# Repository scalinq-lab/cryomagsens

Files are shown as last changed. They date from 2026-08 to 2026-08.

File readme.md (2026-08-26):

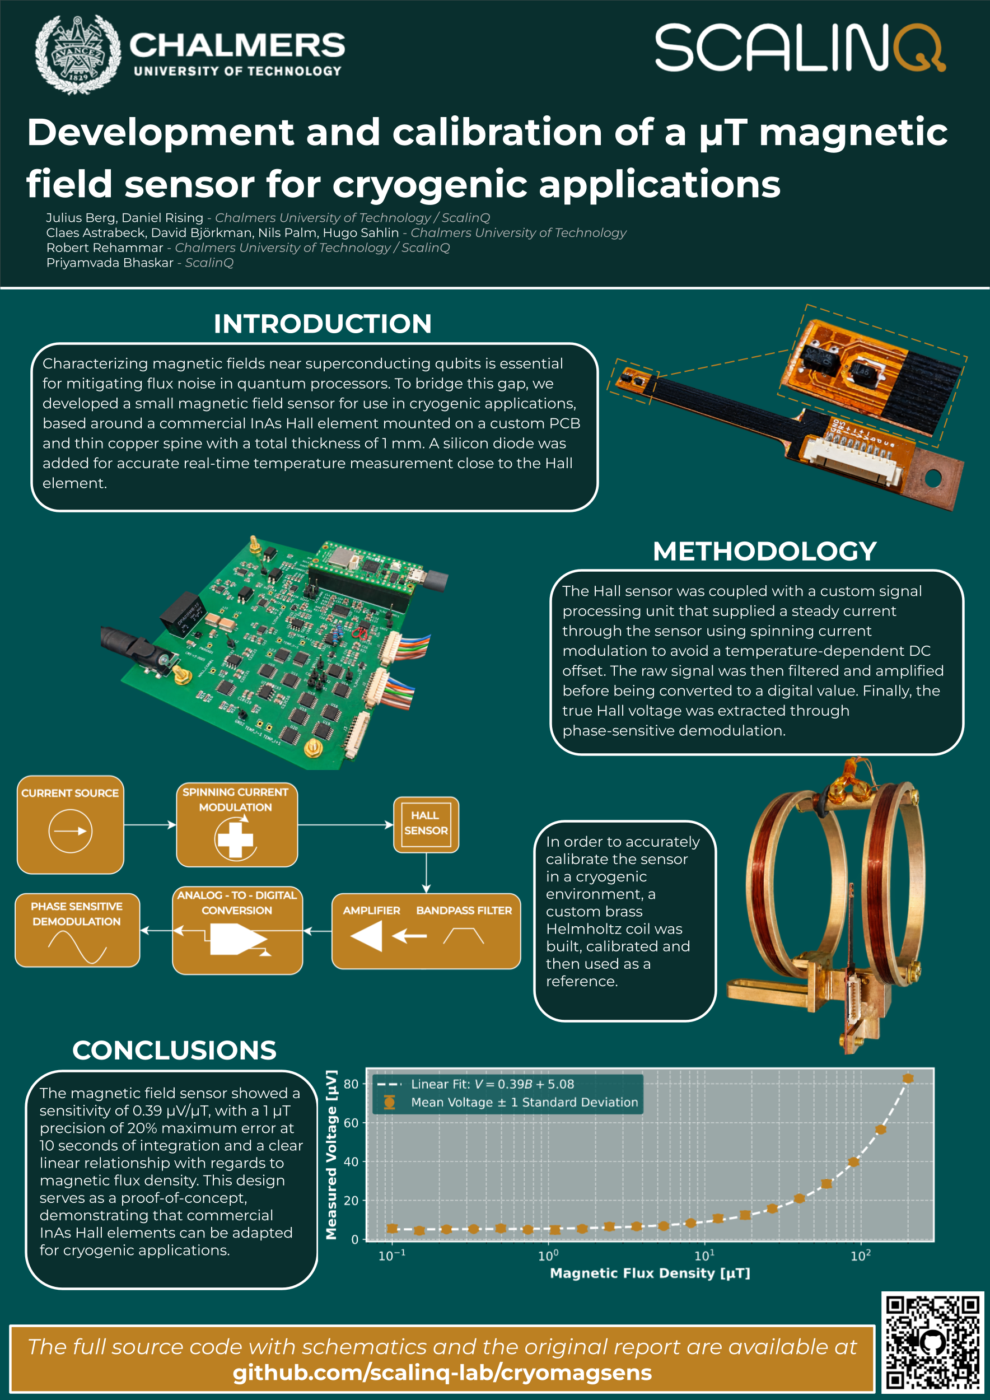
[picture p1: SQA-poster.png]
Photo of the poster from SQA

*(Poster from presentation at SQA conference 2026)*

# Cryomagsens

## Project History
This repository is [SCALINQ AB's](https://www.scalinq.com/) continuation of a project that originally began as a Bachelor's Thesis project at the 
 [Department of Microtechnology and Nanoscience at Chalmers University of Technology](https://www.chalmers.se/en/departments/mc2/), 
 in collaboration with SCALINQ AB.

The original proof-of-concept repository can be referenced for historical context [here](
https://github.com/cryomagsens/cryomagsens)

## Description
Cryomagsens is a magnetic field sensor, developed specifically for cryogenic applications. It features a custom sensor 
built around the AKM HQ0811 InAs Hall effect sensor with an integrated temperature sensor and a custom signal processing
unit (SPU), using phase sensitive detection to extract the signal. The signal processing unit is built around the 
Raspberry Pi Pico 2W microcontroller development board, and features hardware support for measurements with 3 different 
sensor units at once.

The system also includes a custom built brass Helmholtz coil for controlled calibration in a cryogenic environment.

All PCB design files for the signal processing unit can be found in `/signal_processing_unit_pcb`, 
and all the PCB design files for the sensor unit can be found in `/sensor_unit_pcb`.

All the mechanical files for the Helmholtz coil and custom PCB mounts can be found in `/mechanical_designs`.

The signal processing unit firmware can be found in `/signal_processing_unit_firmware` and the calibration and test
scripts can be found in `/calibration_scripts`.

## Results
Experimental results show a sensitivity of 0.39 V/T at 5.2 K and 300 µA drive current, with a 20 % relative error at 1 µT.

## Known issues
During work with the project, we have encountered the following problems:

* When running the calibration system at low temperatures, significant self heating occurs. The sensor itself has a low thermal load for currents up to 3 mA through the hall sensor, but thermalizes badly through the brass Helmholtz coil.
* After spinning current demodulation, a significant DC component remains to the signal, corresponding to ~10 µT of signal strenght.
* Uncertain temperature calibration, as mounting point for external temperature sensor is far from the integrated sensor.
* Possible self-induced magnetic fields on the sensor PCB due to signal path asymmetry.

The following is a list of non implemented features.
* No check for current source saturation (even though the signal processing unit has hardware support for such a check)
* No way to load calibration data to the SPU. Right now the SPU returns a voltage instead of a magnetic flux density.
* PCB design mistakes (fixed in the PCB design files but visible in the pictures).

The following is a list of proposed changes:
* Implement way to disable/enable current sources to the Hall element and diode independently without interfering with the ADC.
* Invert the connector signals (J1 - J3 on the signal processing unit PCB - Would make the cables bidirectional even when GND and PRS lines aren't shielded).
* Protect the sensitive signals between ground layers during the full signal path.   

## Licensing
This repository contains both software and hardware design files, licensed separately:

- All software (located in `/signal_processing_unit_firmware` and `/calibration_scripts`) is licensed under the MIT License. See [LICENSE-MIT](LICENSE-MIT).

- All hardware design files (PCB Schematics, Layouts, 3D CAD models, etc.) (located in `/mechanical_designs`, `/sensor_unit_pcb`, and `/signal_processing_unit_pcb`) are licensed under the CERN Open Hardware Licence Version 2 - Permissive. See [LICENSE-CERN-OHL-P](LICENSE-CERN-OHL-P).

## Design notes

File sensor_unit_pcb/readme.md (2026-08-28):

# Sensor unit: Schematics and PCB Design

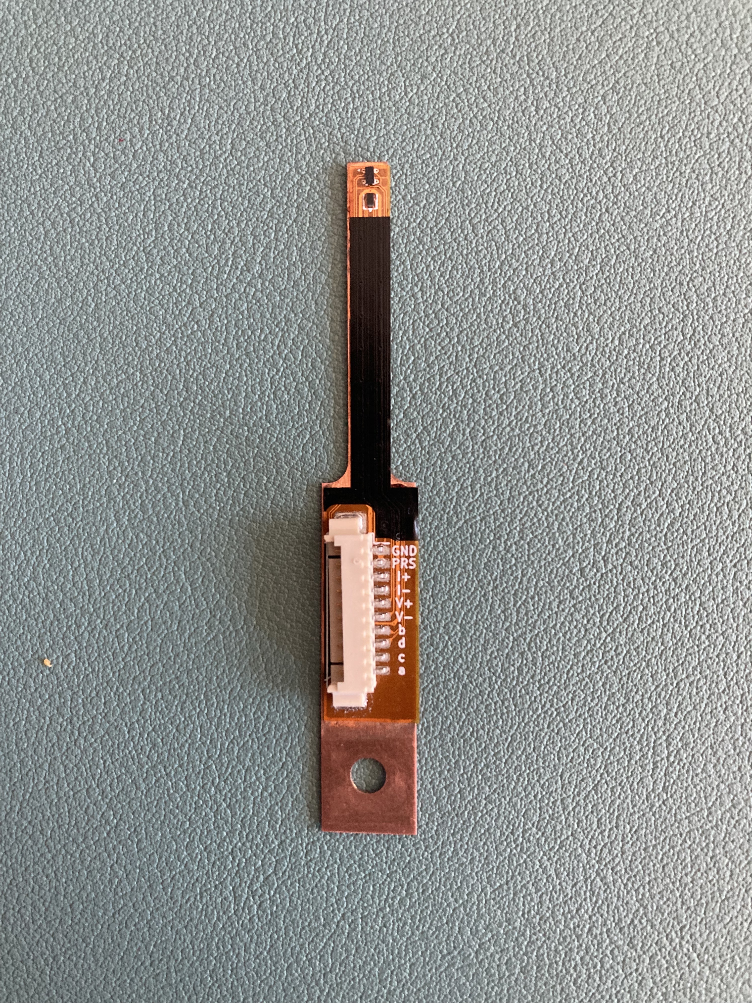
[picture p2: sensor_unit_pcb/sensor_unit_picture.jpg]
Sensor unit

*(Sensor unit)*

## Design

The sensor unit was designed in KiCad 10 and manufactured by JLCPCB. It is built in a flex PCB material to achieve 
a very small build height, in order to come very close to the device under test. The Flex PCB is mounted to a copper 
spine (see `..\mechanical_designs` for the full design) for thermalisation purposes. The total build height of the sensor unit is 1.1 mm.

The sensor unit features a AKM HQ0811 InAs Hall element as a magnetic field sensor, a 1N4148 Si diode as a temperature sensor and a 10-pin Molex PicoBlade connector for a good and stable connection.

## Working principle

### Hall sensor
The Hall element has four nodes, here denoted *a, b, c, d*. When a current is pushed fron *a* to *c*, a potential difference can be measured between *b* and *d*, which scales linearly with the applied orthogonal magnetic flux density.
When a current is pushed from *b* to *d*, a similar potential difference can be measured between *a* and *c*.
By modulating the current directiion and through which axis the current is pushed, the remaining DC offset due to asymmetries in the element can be eliminated.

### Diode temperature sensor
The sensor unit also features a 4-wire measurement setup for the diode, which acts as a temperature sensor.
The nominal drive current of the diode is 10 µA.

### Presence pin.
The sensor unit features a presence pin *(denoted PRS)*, which is internally connected to the ground pin on the sensor PCB.
When connected to the signal processing unit, a GPIO pin is pulled low through the sensor unit, indicating that 
a sensor is connected and allowing current output.

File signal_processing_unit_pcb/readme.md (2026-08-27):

# Signal Processing Unit: Schematics and PCB Design

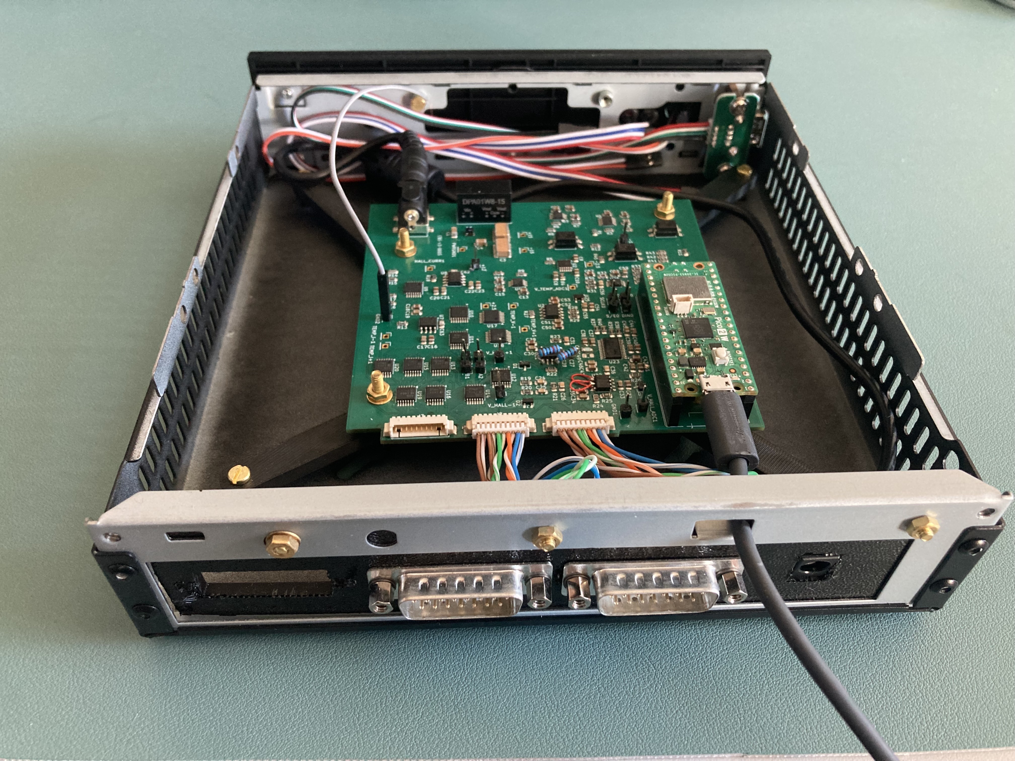
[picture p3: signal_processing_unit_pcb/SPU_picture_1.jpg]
Signal processing unit

*(Assembled signal processing unit)*

## Design

The signal processing unit *(SPU)* was designed in KiCad 10 and manufactured by JLCPCB. It is based around the Raspberry Pi Pico 2W development board and features hardware support for simultaneous magnetic field measurements from three separate cryomagsens sensor units. 

The SPU supports both USB and WiFi interfacing and is physically grounded to the chassis to minimize noise. Custom 3D models for components outside of the standard KiCad libraries were sourced from the SamacSys Library Loader.

## Cabling

The board features three 10-pin Molex PicoBlade connectors. These route to external 15-pin D-sub connectors on the enclosure to ensure a secure physical connection.

## Known Issues 

There are three known design mistakes on the physical PCB shown above. **Note:** All three issues have been corrected in the provided KiCad schematic and PCB design files.

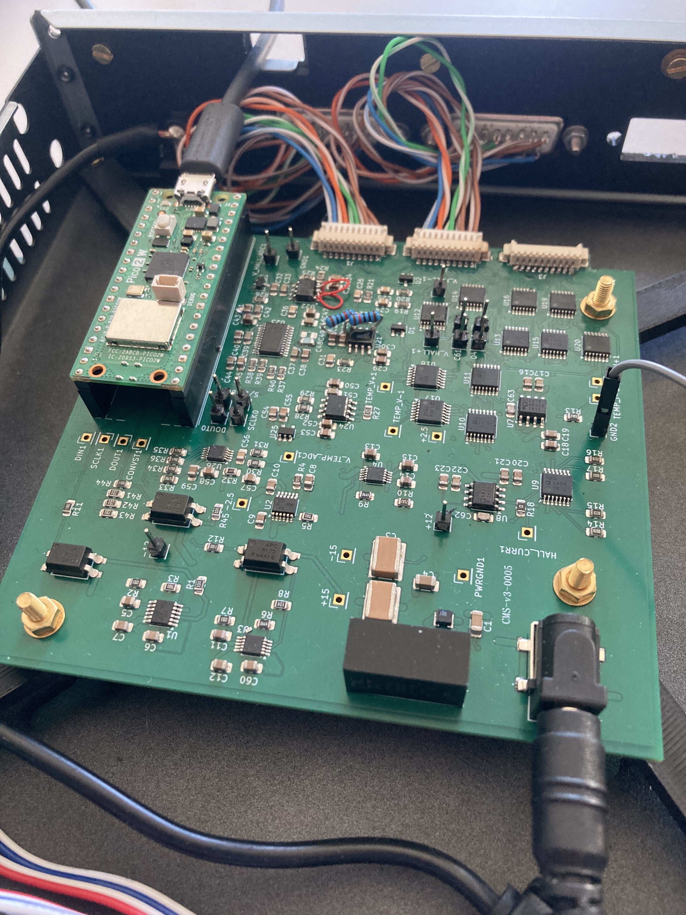
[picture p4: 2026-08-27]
signal_processing_unit_pcb/SPU_picture_0.jpg

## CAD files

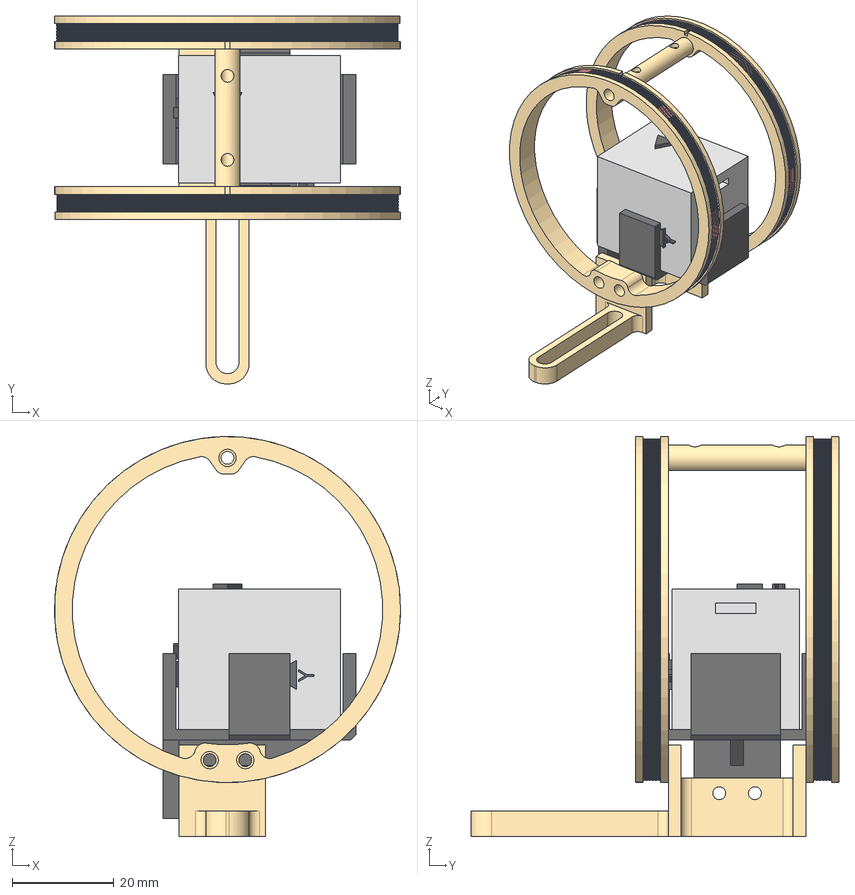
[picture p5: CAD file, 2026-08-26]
mechanical_designs/coil_calibration_assembly.step
68.0 x 72.2 x 78.6 mm
coil x 2
Coil Mount

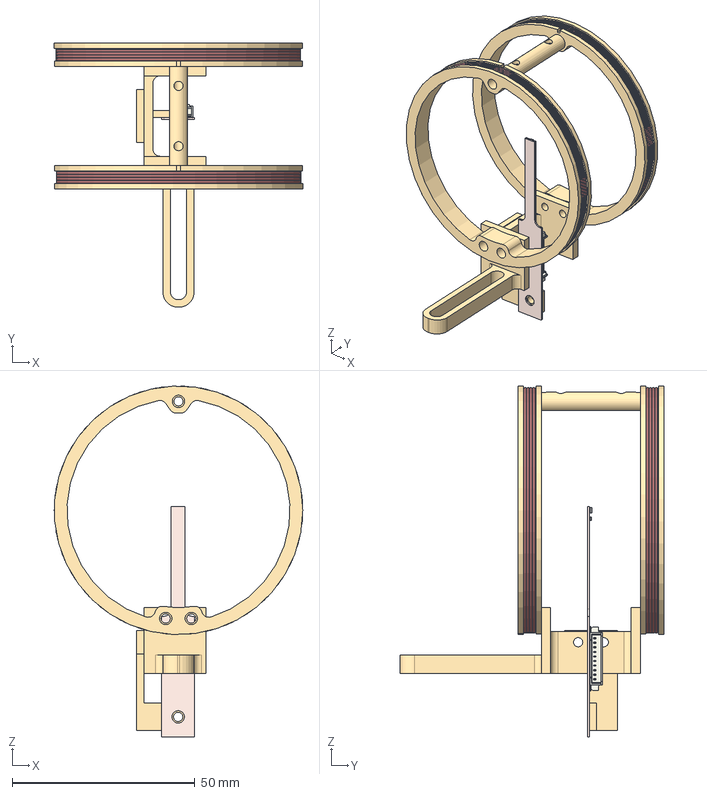
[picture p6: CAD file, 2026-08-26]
mechanical_designs/sensor_calibration_assembly.step
68.0 x 72.2 x 96.0 mm
coil x 2
Coil Mount
Molex_53261_1071
Pins
D_SOD-882_1
Sen1F3C_copper
Sen1F3C_pad
Sen1F3C_via
Sen1F3C_silkscreen
Sen1F3C_soldermask
Sen1F3C_soldermask_1
Sen1F3C_PCB

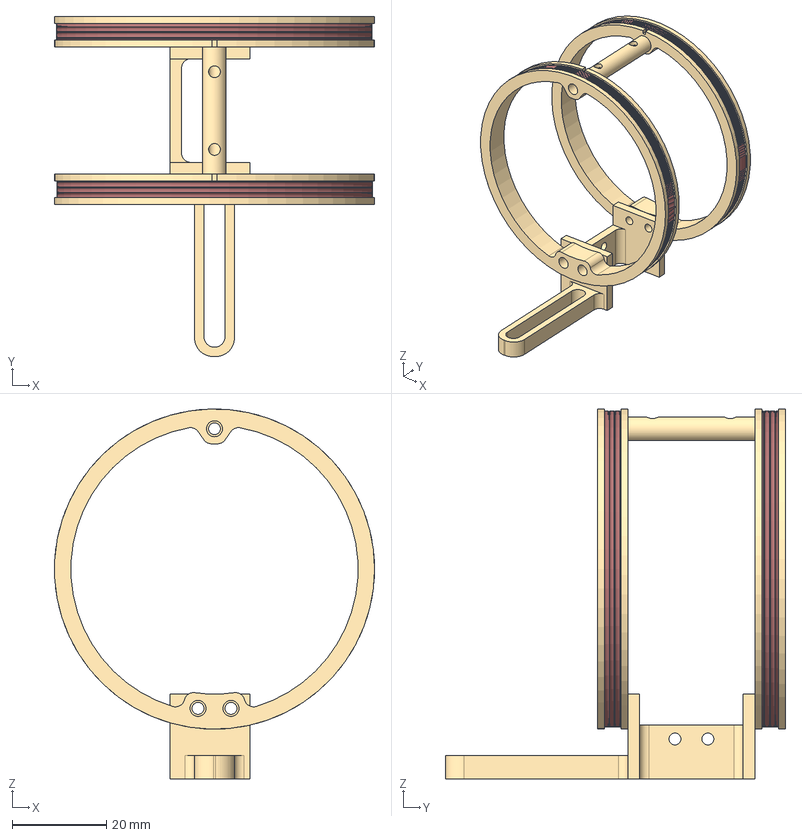
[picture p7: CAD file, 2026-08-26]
mechanical_designs/helmholtz_coil/helmholtz_coil_assembly.step
68.0 x 72.2 x 78.6 mm
coil x 2
Coil Mount

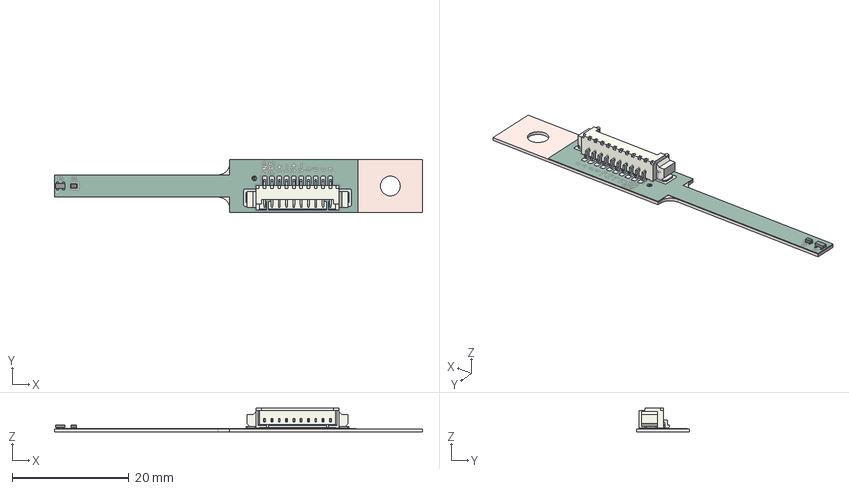
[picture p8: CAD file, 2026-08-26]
mechanical_designs/sensor_unit/sensorunit_assembly.step
63.0 x 9.00 x 4.05 mm
Molex_53261_1071
Pins
D_SOD-882_1
Sen1F3C_copper
Sen1F3C_pad
Sen1F3C_via
Sen1F3C_silkscreen
Sen1F3C_soldermask
Sen1F3C_soldermask_1
Sen1F3C_PCB

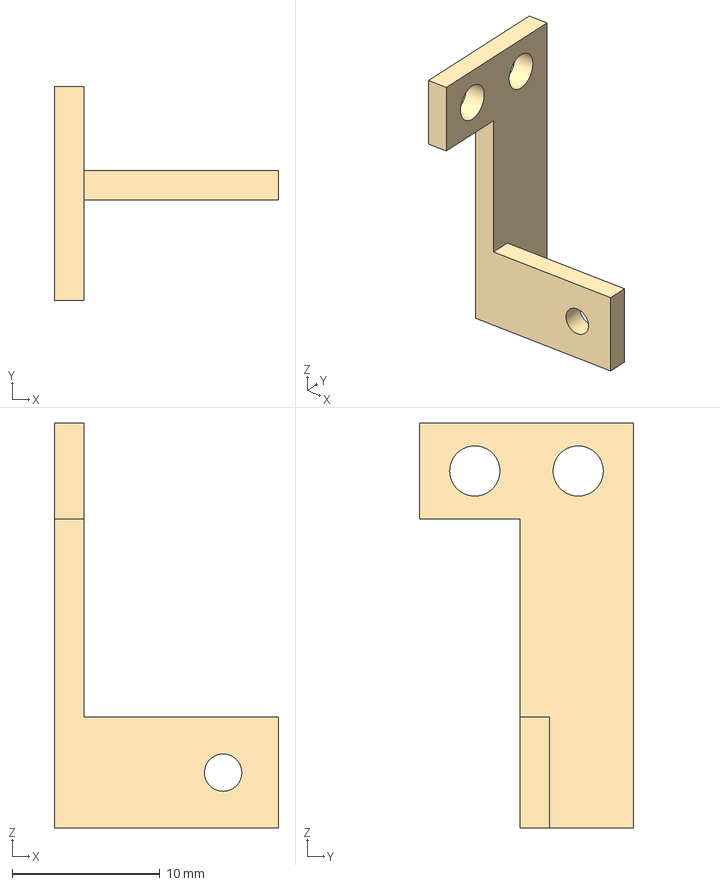
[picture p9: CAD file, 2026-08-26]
mechanical_designs/adapters_and_tools/sensorunit_adapter.step
15.2 x 14.5 x 27.4 mm

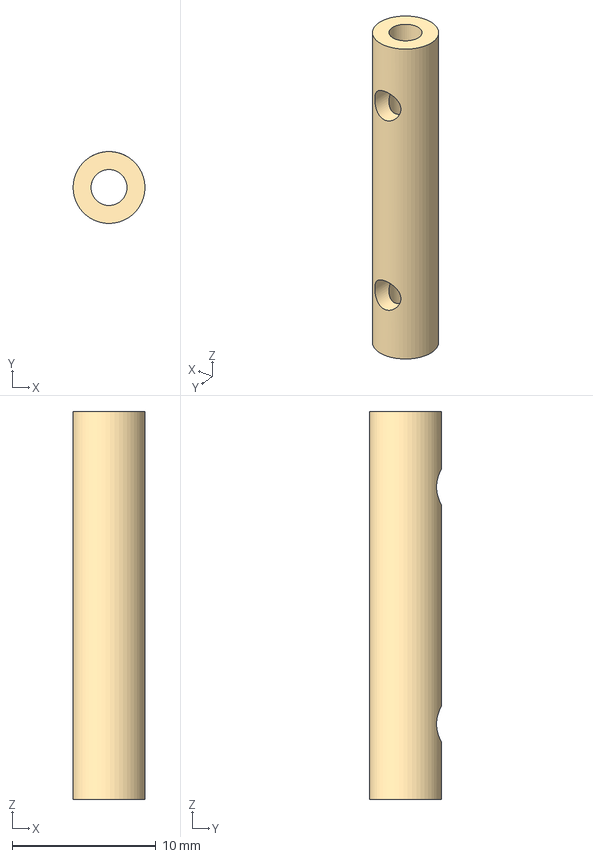
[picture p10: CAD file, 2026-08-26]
mechanical_designs/helmholtz_coil/coil_spacer.step
5.00 x 5.00 x 27.0 mm

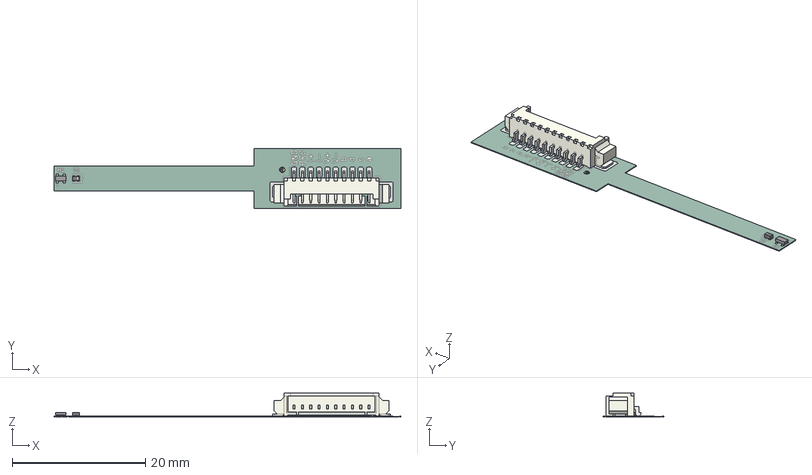
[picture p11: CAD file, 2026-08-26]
mechanical_designs/sensor_unit/sensorunit_pcba.step
52.0 x 9.00 x 3.55 mm
Molex_53261_1071
Pins
D_SOD-882_1
Sen1F3C_copper
Sen1F3C_pad
Sen1F3C_via
Sen1F3C_silkscreen
Sen1F3C_soldermask
Sen1F3C_soldermask_1
Sen1F3C_PCB

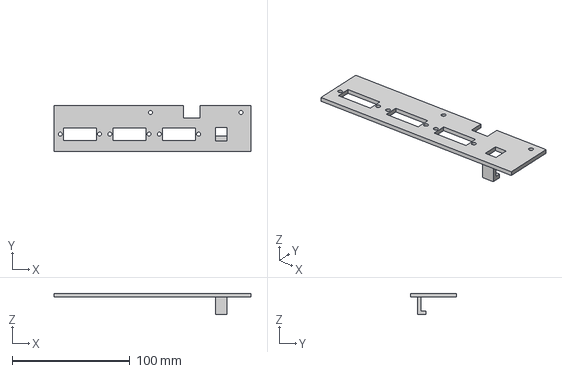
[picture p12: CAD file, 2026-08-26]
mechanical_designs/signal_processing_unit/spu_io_shield.step
167.0 x 39.0 x 18.0 mm

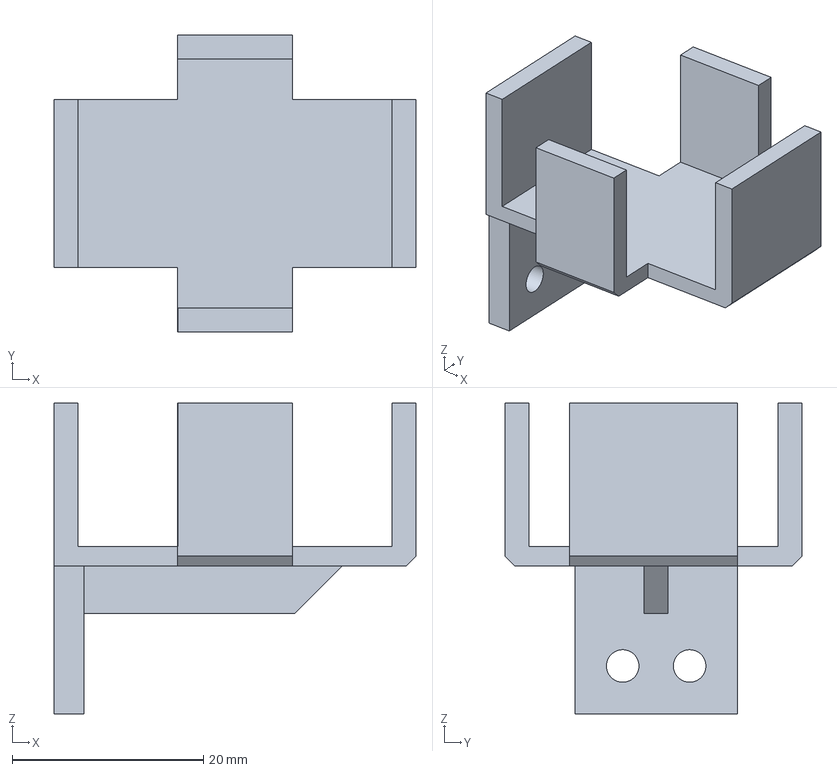
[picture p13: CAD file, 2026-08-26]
mechanical_designs/adapters_and_tools/alphalab_mr3_adapter.step
37.9 x 31.0 x 32.5 mm

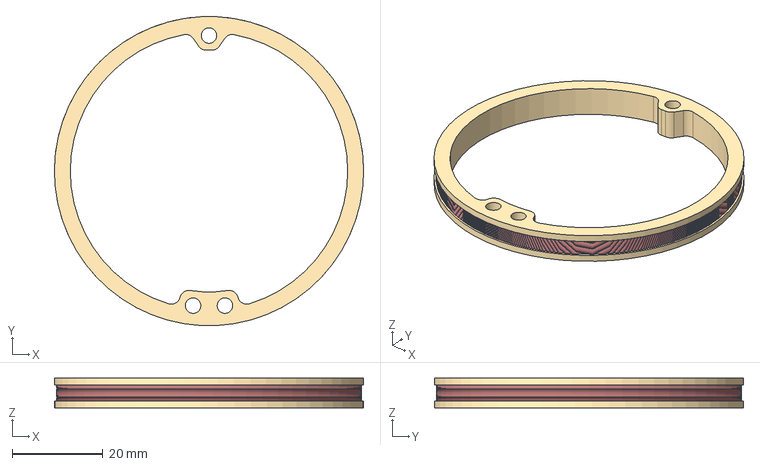
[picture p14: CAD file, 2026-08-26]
mechanical_designs/helmholtz_coil/coil.step
68.0 x 67.9 x 6.50 mm

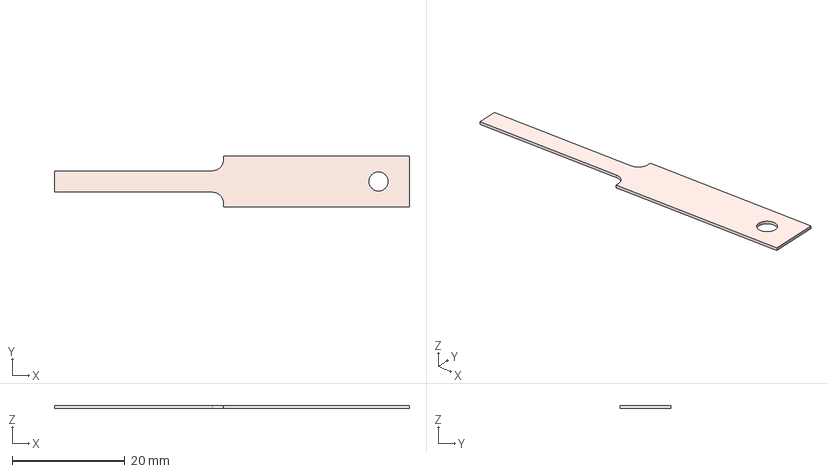
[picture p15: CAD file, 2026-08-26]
mechanical_designs/sensor_unit/sensorunit_spine.step
63.0 x 9.00 x 0.5 mm

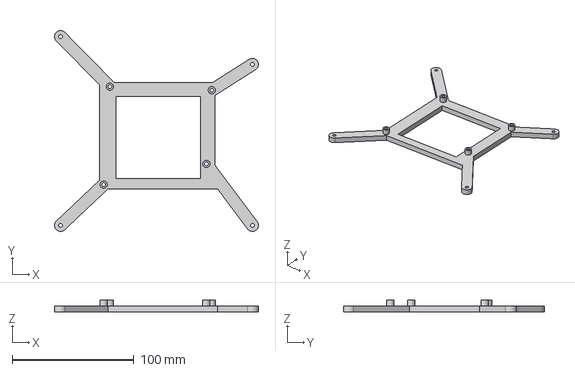
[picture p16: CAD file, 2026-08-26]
mechanical_designs/signal_processing_unit/spu_bracket.step
167.5 x 164.9 x 10.0 mm

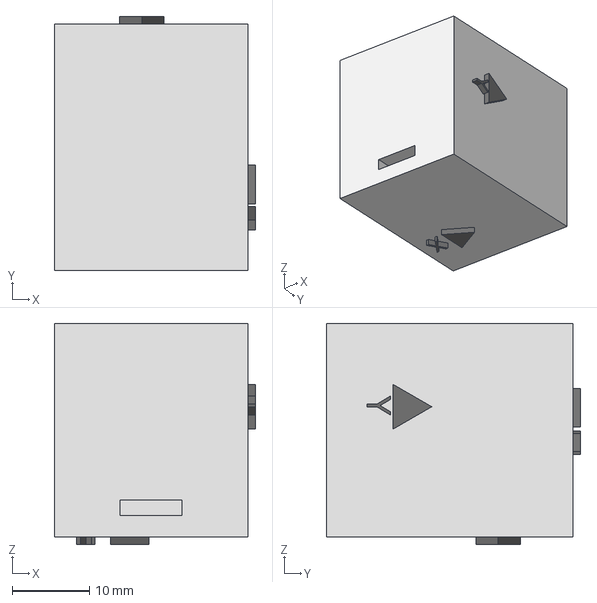
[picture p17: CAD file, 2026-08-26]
mechanical_designs/adapters_and_tools/alphalab_mr3_recreation.step
26.0 x 32.9 x 28.6 mm

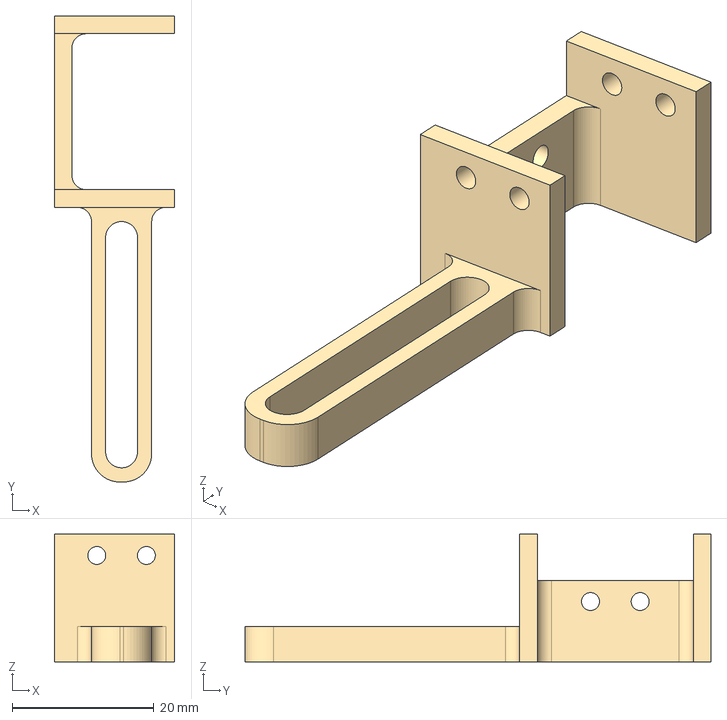
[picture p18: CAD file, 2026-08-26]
mechanical_designs/helmholtz_coil/coil_mount.step
17.0 x 65.8 x 18.0 mm

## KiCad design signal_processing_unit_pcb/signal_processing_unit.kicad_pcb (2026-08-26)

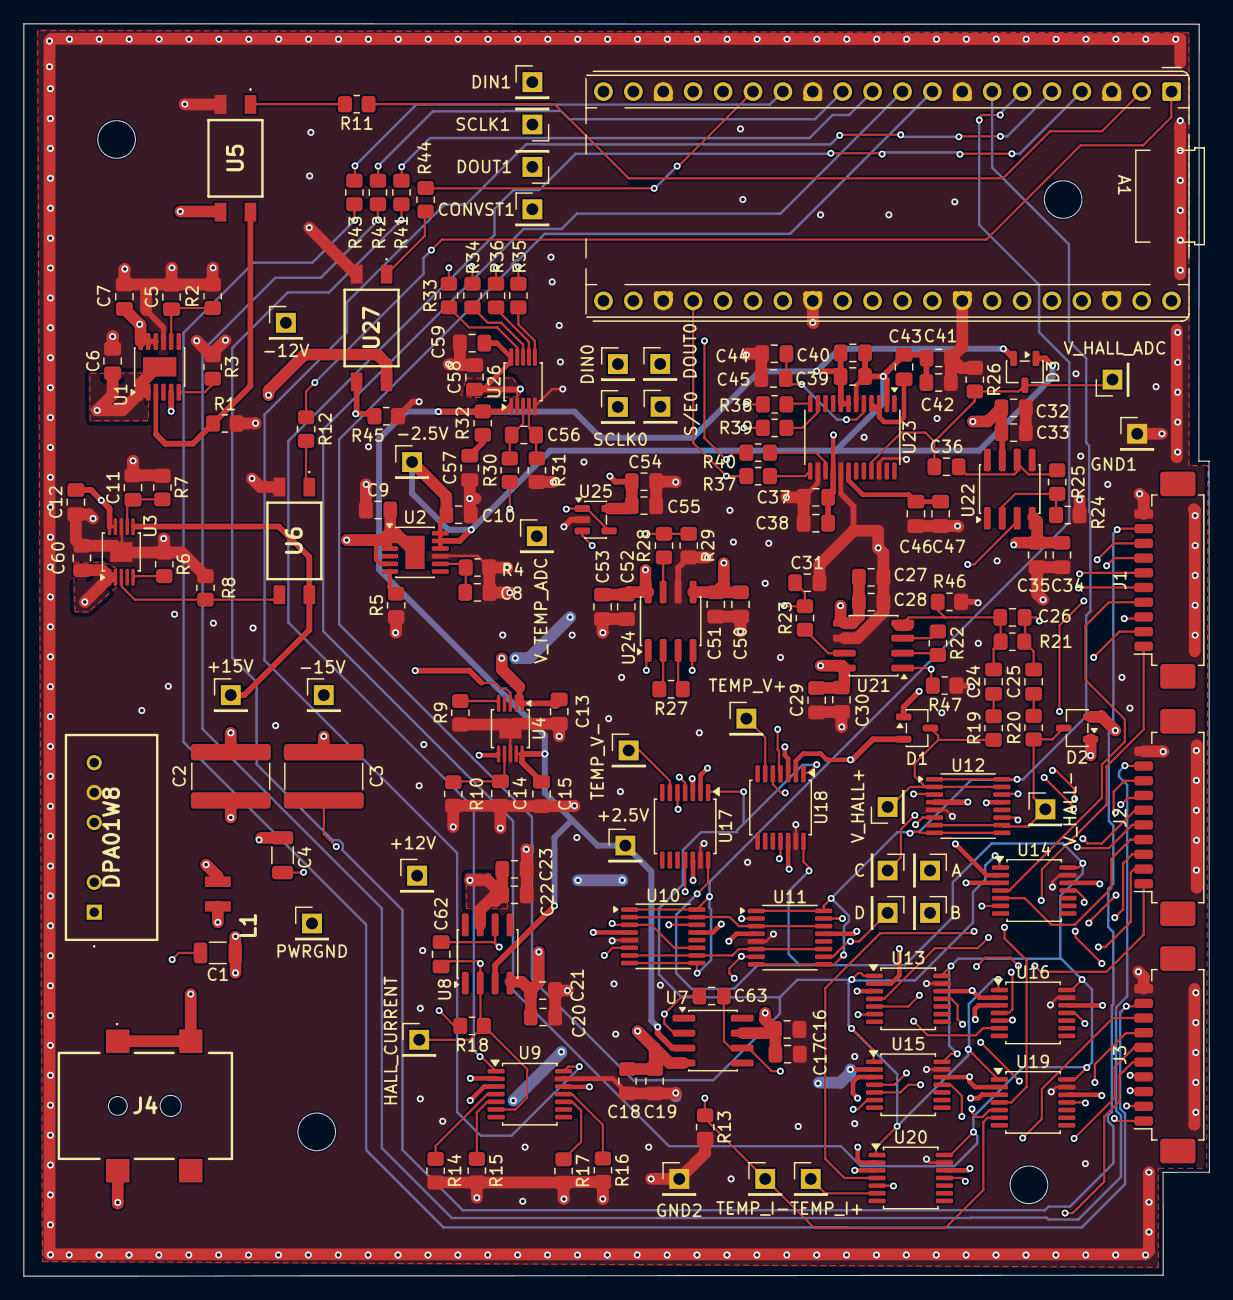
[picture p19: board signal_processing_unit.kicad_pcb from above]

Board: 6 copper layers, 100.7 x 106.4 mm, 178 parts (0 on the bottom side), 121 nets.

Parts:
+2.5: +2.5V; PinHeader_1x01_P2.54mm_Vertical
+12: +12V; PinHeader_1x01_P2.54mm_Vertical
+15: +15V; PinHeader_1x01_P2.54mm_Vertical
-2.5: -2.5V; PinHeader_1x01_P2.54mm_Vertical
-12: -12V; PinHeader_1x01_P2.54mm_Vertical
-15: -15V; PinHeader_1x01_P2.54mm_Vertical
A1: RaspberryPi_Pico; Raspberry_Pi_Pico_mod
A2: A; PinHeader_1x01_P2.54mm_Vertical
B1: B; PinHeader_1x01_P2.54mm_Vertical
C1, C4: 2.2uF/100V; C_1206_3216Metric
C2, C3: 1,5nF/5KV; C_1825_4564Metric
C5, C8, C12, C13, C15, C60: 4,7uF; C_0805_2012Metric_Pad1.18x1.45mm_HandSolder
C6, C7, C9, C10, C16, C18, C20, C23, C27, C29, C32, C35, C38, C40, C41, C50, C53, C54, C57: 10µF; C_0805_2012Metric_Pad1.18x1.45mm_HandSolder
C11, C14: 470n; C_0805_2012Metric_Pad1.18x1.45mm_HandSolder
C17, C19, C21, C22, C28, C30, C33, C34, C37, C39, C42, C44, C46, C51, C52, C55: 100nF; C_0805_2012Metric_Pad1.18x1.45mm_HandSolder
C24, C25: 10nF; C_0805_2012Metric_Pad1.18x1.45mm_HandSolder
C26: 47nF; C_0805_2012Metric_Pad1.18x1.45mm_HandSolder
C31, C56: 10n; C_0805_2012Metric_Pad1.18x1.45mm_HandSolder
C36: 47n; C_0805_2012Metric_Pad1.18x1.45mm_HandSolder
C43: 4.7µF; C_0805_2012Metric_Pad1.18x1.45mm_HandSolder
C45, C47, C58, C59: 1µF; C_0805_2012Metric_Pad1.18x1.45mm_HandSolder
C61: C; PinHeader_1x01_P2.54mm_Vertical
C62, C63: 22pF; C_0805_2012Metric_Pad1.18x1.45mm_HandSolder
CONVST1: CONVST1; PinHeader_1x01_P2.54mm_Vertical
D1, D2, D3: BAV199-7-F; SOT-23-3
D4: D; PinHeader_1x01_P2.54mm_Vertical
DIN0: DIN0; PinHeader_1x01_P2.54mm_Vertical
DIN1: DIN1; PinHeader_1x01_P2.54mm_Vertical
DOUT0: DOUT0; PinHeader_1x01_P2.54mm_Vertical
DOUT1: DOUT1; PinHeader_1x01_P2.54mm_Vertical
DPA01W8: DPA01W815
GND1: GND1; PinHeader_1x01_P2.54mm_Vertical
GND2: GND2; PinHeader_1x01_P2.54mm_Vertical
H1, H2, H3, H4: MountingHole; MountingHole_3.2mm_M3
HALL_CURR1: HALL_CURRENT; PinHeader_1x01_P2.54mm_Vertical
J1, J2, J3: Conn_01x10_Pin; Molex_PicoBlade_53261-1071_1x10-1MP_P1.25mm_Horizontal
J4: 54-00164; DC_plug
L1: WE-RFH_1008A; WE-RFH68
PWRGND1: PWRGND; PinHeader_1x01_P2.54mm_Vertical
R1, R8, R45: 100 K; R_0805_2012Metric_Pad1.20x1.40mm_HandSolder
R2, R7: 120k; R_0805_2012Metric_Pad1.20x1.40mm_HandSolder
R3, R5: 7.5k; R_0805_2012Metric_Pad1.20x1.40mm_HandSolder
R4, R10: 25 K; R_0805_2012Metric_Pad1.20x1.40mm_HandSolder
R6, R9: 499; R_0805_2012Metric_Pad1.20x1.40mm_HandSolder
R11, R12, R44: 330; R_0805_2012Metric_Pad1.20x1.40mm_HandSolder
R13: 250k; R_0805_2012Metric_Pad1.20x1.40mm_HandSolder
R14: 820; R_0805_2012Metric_Pad1.20x1.40mm_HandSolder
R15: 8.2k; R_0805_2012Metric_Pad1.20x1.40mm_HandSolder
R16: 82k; R_0805_2012Metric_Pad1.20x1.40mm_HandSolder
R17: 300; R_0805_2012Metric_Pad1.20x1.40mm_HandSolder
R18: 0; R_0805_2012Metric_Pad1.20x1.40mm_HandSolder
R19, R20, R23: 470; R_0805_2012Metric_Pad1.20x1.40mm_HandSolder
R21: 3.3k; R_0805_2012Metric_Pad1.20x1.40mm_HandSolder
R22: 100; R_0805_2012Metric_Pad1.20x1.40mm_HandSolder
R24, R41, R42, R43: 1k; R_0805_2012Metric_Pad1.20x1.40mm_HandSolder
R25, R28, R29, R46, R47: 10k; R_0805_2012Metric_Pad1.20x1.40mm_HandSolder
R26: 1.6k; R_0805_2012Metric_Pad1.20x1.40mm_HandSolder
R27: 1M; R_0805_2012Metric_Pad1.20x1.40mm_HandSolder
R30, R31: 10; R_0805_2012Metric_Pad1.20x1.40mm_HandSolder
R32: 0.47; R_0805_2012Metric_Pad1.20x1.40mm_HandSolder
R33, R34, R35, R36, R37, R38, R39, R40: 47; R_0805_2012Metric_Pad1.20x1.40mm_HandSolder
S/E0: S/E0; PinHeader_1x01_P2.54mm_Vertical
SCLK0: SCLK0; PinHeader_1x01_P2.54mm_Vertical
SCLK1: SCLK1; PinHeader_1x01_P2.54mm_Vertical
TEMP_I+1: TEMP_I+; PinHeader_1x01_P2.54mm_Vertical
TEMP_I-1: TEMP_I-; PinHeader_1x01_P2.54mm_Vertical
TEMP_V+1: TEMP_V+; PinHeader_1x01_P2.54mm_Vertical
TEMP_V-1: TEMP_V-; PinHeader_1x01_P2.54mm_Vertical
U1, U2: LT3094xMSE; MSOP-12-1EP_3x4.039mm_P0.65mm_EP1.651x2.845mm
U3, U4: LT3042xMSE; MSOP-10-1EP_3x3mm_P0.5mm_EP1.68x1.88mm
U5, U6, U27: APC817D1SL
U7, U8, U22: AD8675ARZ; SOIC-8_3.9x4.9mm_P1.27mm
U9, U13, U14, U15, U16, U17, U18, U19, U20: ADG1404; TSSOP-14_4.4x5mm_P0.65mm
U10, U11, U12: ADG1413; TSSOP-16_4.4x5mm_P0.65mm
U21, U24: AD8421ARZ; SOIC-8_3.9x4.9mm_P1.27mm
U23: AD7175-2BRUZ; TSSOP-24_4.4x7.8mm_P0.65mm
U25: AD8603; TSOT-23-5
U26: ADS8866; MSOP-10_3x3mm_P0.5mm
V_HALL+1: V_HALL+; PinHeader_1x01_P2.54mm_Vertical
V_HALL-1: V_HALL-; PinHeader_1x01_P2.54mm_Vertical
V_HALL_ADC1: V_HALL_ADC; PinHeader_1x01_P2.54mm_Vertical
V_TEMP_ADC1: V_TEMP_ADC; PinHeader_1x01_P2.54mm_Vertical

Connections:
15V: C1.1, J4.A1, J4.A2, L1.1
+2.5V: +2.5.1 (1_1), C15.2, C39.2, C40.2, D3.2 (K2), R32.1, U4.9 (OUTS), U4.10 (OUT), U7.3 (+), U8.3 (+), U23.7 (AVDD1), U23.8 (AVDD2), U26.1 (REF)
+3.3V: A1.36 (3V3), C37.1, C38.1, C54.1, C55.2, C58.2, C59.1, U23.16 (IOVDD), U25.5 (V+), U26.2 (AVDD), U26.10 (DVDD)
+12V: +12.1 (1_1), C12.2, C13.2, C16.2, C17.2, C22.2, C23.2, C29.2, C30.2, C32.2, C33.2, C52.2, C53.2, D1.2 (K2), D2.2 (K2), U3.9 (OUTS), U3.10 (OUT), U4.1 (IN), U4.2 (IN), U4.6 (PGFB), U7.7 (V+), U8.7 (V+), U9.2 (EN), U9.12 (VDD), U10.13 (VDD), U11.13 (VDD), U12.13 (VDD), U13.2 (EN), U13.12 (VDD), U14.2 (EN), U14.12 (VDD), U15.2 (EN), U15.12 (VDD), U16.2 (EN), U16.12 (VDD), U17.2 (EN), U17.12 (VDD), U18.2 (EN), U18.12 (VDD), U19.2 (EN), U19.12 (VDD), U20.2 (EN), U20.12 (VDD), U21.8 (Vs+), U22.7 (V+), U24.8 (Vs+), U27.4 (CLCTR)
+15V: +15.1 (1_1), C2.2, C60.2, DPA01W8.4 (Vout+), U3.1 (IN), U3.2 (IN), U3.6 (PGFB), U6.4 (CLCTR)
-2.5V: -2.5.1 (1_1), C10.2, C39.1, C40.1, C41.1, C42.1, C43.2, D3.1 (A1), U2.10 (OUTS), U2.11 (OUT), U2.12 (OUT), U23.2 (REF-), U23.6 (AVSS)
-12V: -12.1 (1_1), C7.2, C9.2, C18.2, C19.2, C20.2, C21.2, C27.2, C28.2, C34.2, C35.2, C50.2, C51.2, D1.1 (A1), D2.1 (A1), U1.10 (OUTS), U1.11 (OUT), U1.12 (OUT), U2.1 (IN), U2.2 (IN), U2.3 (EN/UV), U2.5 (PGFB), U2.13 (IN), U7.4 (V-), U8.4 (V-), U9.3 (Vss), U10.4 (VSS), U11.4 (VSS), U12.4 (VSS), U13.3 (Vss), U14.3 (Vss), U15.3 (Vss), U16.3 (Vss), U17.3 (Vss), U18.3 (Vss), U19.3 (Vss), U20.3 (Vss), U21.5 (Vs-), U22.4 (V-), U24.5 (Vs-)
-15V: -15.1 (1_1), C3.2, C6.2, DPA01W8.6 (Vout-), U1.1 (IN), U1.2 (IN), U1.5 (PGFB), U1.13 (IN), U5.3 (EMTR)
/2.5V_CTRL: A1.15 (GPIO11), R44.2
/CONN0: A1.9 (GPIO6), U13.1 (A0), U14.1 (A0), U15.1 (A0), U16.1 (A0), U17.1 (A0), U18.1 (A0), U19.1 (A0), U20.1 (A0)
/CONN1: A1.10 (GPIO7), U13.14 (A1), U14.14 (A1), U15.14 (A1), U16.14 (A1), U17.14 (A1), U18.14 (A1), U19.14 (A1), U20.14 (A1)
/CURR_CTRL0: A1.4 (GPIO2), U9.1 (A0)
/CURR_CTRL1: A1.5 (GPIO3), U9.14 (A1)
/HALL_CTRL0: A1.6 (GPIO4), U10.1 (IN1), U10.8 (IN4), U10.9 (IN3), U10.16 (IN2)
/HALL_CTRL1: A1.7 (GPIO5), U11.1 (IN1), U11.8 (IN4), U11.9 (IN3), U11.16 (IN2), U12.1 (IN1), U12.8 (IN4), U12.9 (IN3), U12.16 (IN2)
/Hall_voltage: C36.2, D3.3 (K1/A2), R26.2, U23.21 (AIN0), V_HALL_ADC1.1 (1_1)
/I+: C63.1, TEMP_I+1.1 (1_1), U7.6 (OUT), U20.6 (D)
/I+0: J1.8, U20.4 (S1)
/I+1: J2.8, U20.5 (S2)
/I+2: J3.8, U20.11 (S3)
/I-: C63.2, R13.1, TEMP_I-1.1 (1_1), U7.2 (-), U19.6 (D)
/I-0: J1.7, U19.4 (S1)
/I-1: J2.7, U19.5 (S2)
/I-2: J3.7, U19.11 (S3)
/LINREGG_ON0: A1.1 (GPIO0), R12.1
/LINREGG_ON1: A1.2 (GPIO1), R11.1
/PICO_ADC_0: A1.31 (GPIO26_ADC0), R18.2
/PRES0: J1.9, R41.1
/PRES1: J2.9, R42.1
/PRES2: J3.9, R43.1
/SPI0_*SYNC/*ERROR: A1.22 (GPIO17), R40.1, S/E0.1 (1_1)
/SPI0_DIN: A1.25 (GPIO19), DIN0.1 (1_1), R38.1
/SPI0_DOUT: A1.21 (GPIO16), DOUT0.1 (1_1), R39.1
/SPI0_SCLK: A1.24 (GPIO18), R37.1, SCLK0.1 (1_1)
/SPI1_CONVST: A1.17 (GPIO13), CONVST1.1 (1_1), R35.1
/SPI1_DIN: A1.20 (GPIO15), DIN1.1 (1_1), R33.1
/SPI1_DOUT: A1.16 (GPIO12), DOUT1.1 (1_1), R36.1
/SPI1_SCLK: A1.19 (GPIO14), R34.1, SCLK1.1 (1_1)
/V+: TEMP_V+1.1 (1_1), U18.6 (D), U24.4 (+)
/V+0: J1.6, U18.4 (S1)
/V+1: J2.6, U18.5 (S2)
/V+2: J3.6, U18.11 (S3)
/V-: TEMP_V-1.1 (1_1), U17.6 (D), U24.1 (-)
/V-0: J1.5, U17.4 (S1)
/V-1: J2.5, U17.5 (S2)
/V-2: J3.5, U17.11 (S3)
/a: A2.1 (1_1), U11.2 (D1), U12.14 (S2), U13.6 (D)
/a0: J1.1, U13.4 (S1)
/a1: J2.1, U13.5 (S2)
/a2: J3.1, U13.11 (S3)
/b: B1.1 (1_1), U11.15 (D2), U12.3 (S1), U14.6 (D)
/b0: J1.4, U14.4 (S1)
/b1: J2.4, U14.5 (S2)
/b2: J3.4, U14.11 (S3)
/c: C61.1 (1_1), U11.7 (D4), U12.11 (S3), U15.6 (D)
/c0: J1.2, U15.4 (S1)
/c1: J2.2, U15.5 (S2)
/c2: J3.2, U15.11 (S3)
/d: D4.1 (1_1), U11.10 (D3), U12.6 (S4), U16.6 (D)
/d0: J1.3, U16.4 (S1)
/d1: J2.3, U16.5 (S2)
/d2: J3.3, U16.11 (S3)
GND: A1.3 (GND), A1.8 (GND), A1.13 (GND), A1.18 (GND), A1.23 (GND), A1.28 (GND), A1.33 (AGND), A1.38 (GND), C5.2, C6.1, C7.1, C8.2, C9.1, C10.1, C11.2, C12.1, C13.1, C14.2, C15.1, C16.1, C17.1, C18.1, C19.1, C20.1, C21.1, C22.1, C23.1, C27.1, C28.1, C29.1, C30.1, C31.2, C32.1, C33.1, C34.1, C35.1, C37.2, C38.2, C41.2, C42.2, C44.1, C45.1, C46.1, C47.1, C50.1, C51.1, C52.1, C53.1, C54.2, C55.1, C57.1, C58.1, C59.2, C60.1, DPA01W8.5 (Com_(gnd)), GND1.1 (1_1), GND2.1 (1_1), J1.10, J2.10, J3.10, R1.2, R2.1, R3.1, R4.1, R5.1, R6.1, R7.1, R8.2, R9.1, R10.1, R13.2, R14.2, R15.2, R16.2, R17.2, R24.1, R26.1, R29.2, R31.1, R45.2, R46.1, R47.2, U1.9 (GND), U2.9 (GND), U3.8 (GND), U3.11 (GND), U4.8 (GND), U4.11 (GND), U5.2 (CATHODE), U6.2 (CATHODE), U9.13 (GND), U10.5 (GND), U11.5 (GND), U12.5 (GND), U13.13 (GND), U14.13 (GND), U15.13 (GND), U16.13 (GND), U17.13 (GND), U18.13 (GND), U19.13 (GND), U20.13 (GND), U21.6 (Ref), U23.14 (*CS), U23.17 (DGND), U23.22 (AIN1), U24.6 (Ref), U25.2 (V-), U26.5 (GND), U27.2 (CATHODE)
GNDPWR: C1.2, C3.1, C4.2, DPA01W8.1 (Vin-), J4.B1, PWRGND1.1 (1_1)
unnamed: A1.11 (GPIO8), R41.2
unnamed: A1.12 (GPIO9), R42.2
unnamed: A1.14 (GPIO10), R43.2
unnamed: C24.1, R19.2
unnamed: C25.1, R20.2
unnamed: C57.2, R32.2
unnamed: D1.3 (K1/A2), R19.1, U12.2 (D1), U12.15 (D2), V_HALL+1.1 (1_1)
unnamed: D2.3 (K1/A2), R20.1, U12.7 (D4), U12.10 (D3), V_HALL-1.1 (1_1)
unnamed: C2.1, C4.1, DPA01W8.2 (Vin+), L1.2
unnamed: R22.1, U21.3 (Rg)
unnamed: R22.2, U21.2 (Rg)
unnamed: R23.1, U21.7
unnamed: R27.1, U24.3 (Rg)
unnamed: R27.2, U24.2 (Rg)
unnamed: R28.1, U24.7
unnamed: R1.1, U1.3 (EN/UV), U5.4 (CLCTR)
unnamed: R3.2, U1.6 (ILIM)
unnamed: C5.1, R2.2, U1.8 (SET)
unnamed: R5.2, U2.6 (ILIM)
unnamed: C8.1, R4.2, U2.8 (SET)
unnamed: R8.1, U3.3 (EN/UV), U6.3 (EMTR)
unnamed: R6.2, U3.5 (ILIM)
unnamed: C11.1, R7.2, U3.7 (SET)
unnamed: R9.2, U4.5 (ILIM)
unnamed: C14.1, R10.2, U4.7 (SET)
unnamed: R11.2, U5.1 (ANODE)
unnamed: R12.2, U6.1 (ANODE)
unnamed: R14.1, U9.4 (S1)
unnamed: R15.1, U9.5 (S2)
unnamed: R16.1, U9.11 (S3)
unnamed: R17.1, U9.10 (S4)
unnamed: U10.2 (D1), U10.15 (D2), U11.3 (S1), U11.14 (S2)
unnamed: U10.7 (D4), U10.10 (D3), U11.6 (S4), U11.11 (S3)
unnamed: C62.1, U8.6 (OUT), U10.3 (S1), U10.11 (S3)
unnamed: C62.2, HALL_CURR1.1 (1_1), R18.1, U8.2 (-), U9.6 (D), U10.6 (S4), U10.14 (S2)
unnamed: C24.2, C26.1, R21.2, R46.2, U21.4 (+)
unnamed: C25.2, C26.2, R21.1, R47.1, U21.1 (-)
unnamed: C31.1, R23.2, U22.3 (+)
unnamed: R24.2, R25.1, U22.2 (-)
unnamed: C36.1, R25.2, U22.6 (OUT)
unnamed: R40.2, U23.15 (*SYNC/*ERROR)
unnamed: R38.2, U23.12 (DIN)
unnamed: R39.2, U23.11 (DOUT/*RDY)
unnamed: C43.1, U23.3 (REF+), U23.4 (REFOUT)
unnamed: C44.2, C45.2, U23.5 (REGCAPA)
unnamed: C46.2, C47.2, U23.18 (REGCAPD)
unnamed: R37.2, U23.13 (SCLK)
unnamed: R28.2, R29.1, U25.3 (+)
unnamed: R30.1, U25.1, U25.4 (-), V_TEMP_ADC1.1 (1_1)
unnamed: C56.1, R30.2, U26.3 (AIN+)
unnamed: C56.2, R31.2, U26.4 (AIN-)
unnamed: R35.2, U26.6 (CONVST)
unnamed: R33.2, U26.9 (DIN)
unnamed: R36.2, U26.7 (DOUT)
unnamed: R34.2, U26.8 (SCLK)
unnamed: R44.1, U27.1 (ANODE)
unnamed: R45.1, U4.3 (EN/UV), U27.3 (EMTR)

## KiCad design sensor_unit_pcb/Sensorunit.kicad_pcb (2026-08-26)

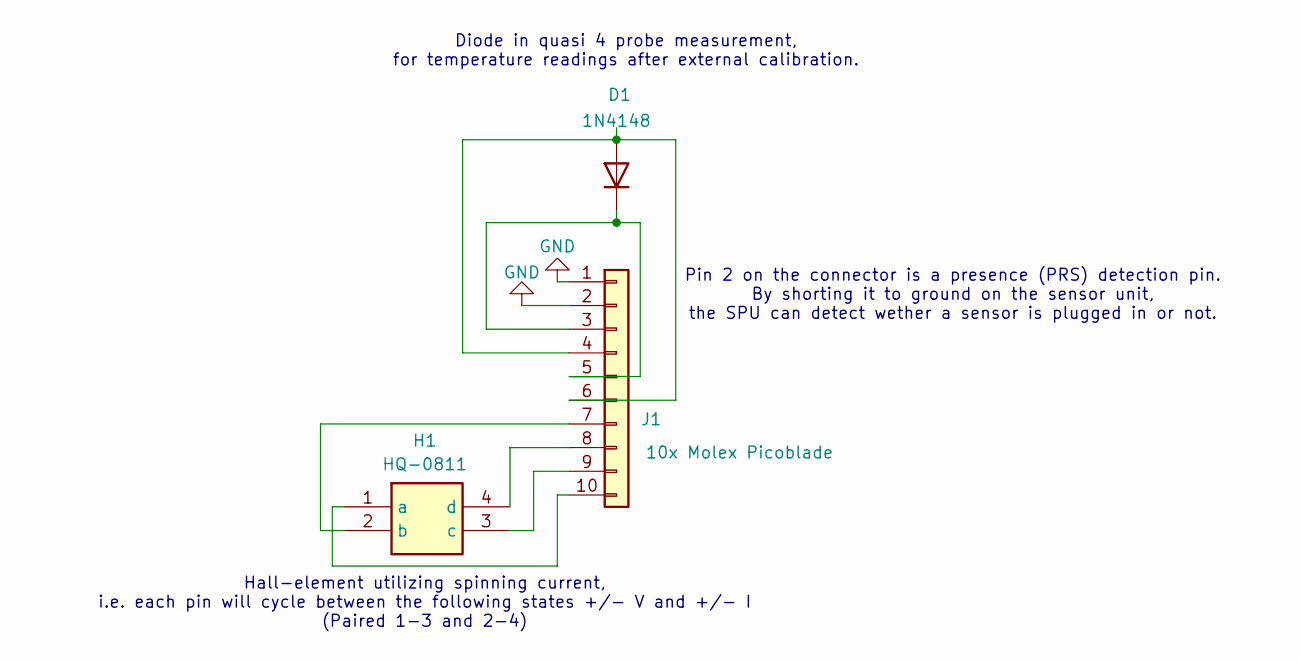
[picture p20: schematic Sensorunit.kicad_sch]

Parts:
D1: 1N4148; D_SOD-882
H1: HQ-0811; HQ0811; Manufacturer_Part_Number HQ-0811
J1: 10x Molex Picoblade; Molex_PicoBlade_53261-1071_1x10-1MP_P1.25mm_Horizontal

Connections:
GND: J1.1, J1.2
unnamed: D1.2 (A), J1.4, J1.6
unnamed: D1.1 (K), J1.3, J1.5
unnamed: H1.1 (a), J1.10
unnamed: H1.2 (b), J1.7
unnamed: H1.3 (c), J1.9
unnamed: H1.4 (d), J1.8

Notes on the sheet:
Hall-element utilizing spinning current, i.e. each pin will cycle between the following states +/- V and +/- I (Paired 1-3 and 2-4)
Pin 2 on the connector is a presence (PRS) detection pin. By shorting it to ground on the sensor unit, the SPU can detect wether a sensor is plugged in or not.
Diode in quasi 4 probe measurement, for temperature readings after external calibration.

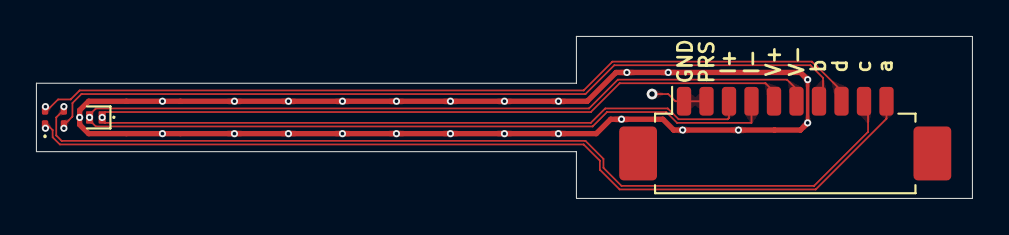
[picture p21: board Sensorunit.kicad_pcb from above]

Board: 2 copper layers, 52.0 x 9.0 mm, 3 parts (0 on the bottom side), 7 nets.

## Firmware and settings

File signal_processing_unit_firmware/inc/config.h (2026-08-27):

// Copyright (c) 2026    ScalinQ AB
//
// This software is released under the MIT License. 
// <https://opensource.org/licenses/MIT>

#pragma once

/* PARAMETERS */
// Hardware parameters
#define ADC_VOLTAGE_REFERENCE 2.5
#define NUMBER_OF_SENSORS 3

// Default operational parameters
#define DEFAULT_INTEGRATION_TIME_MS 1000
#define DEFAULT_CURRENT_POLARITY_FREQUENCY 7000
#define DEFAULT_CURRENT_AXIS_FREQUENCY 70
#define DEFAULT_MODULATION_PROPAGATION_TIME_US 12
#define DEFAULT_MODULATION_UNSTABLE_TIME_US 16
#define DEFAULT_AXIS_UNSTABLE_TIME_US 145 + 224 * 3


/* GPIO/SPI PINOUT */
// Main power enable for the positive and negative supply rails
#define PIN_POWER_ENABLE_POS 0
#define PIN_POWER_ENABLE_NEG 1

// Current multiplexer pins 00: 3mA, 01: 0.3mA, 10: 30uA, 11: 8.3mA
#define PIN_CURRENT_LEVEL_0 2
#define PIN_CURRENT_LEVEL_1 3

// Direction of the current through the sensor (0 = c->a or d->b, 1 = a->c or b->d)
#define PIN_CURRENT_DIRECTION 4

// Axis of the current through the sensor (0 = b&d, 1 = a&c)
#define PIN_CURRENT_AXIS 5

// Sensor multiplexer pins 00: Sensor 0, 01: Sensor 1, 10: Sensor 2, 11: (NOT AN ALLOWED STATE)
#define PIN_SENSOR_MUX_0 6 
#define PIN_SENSOR_MUX_1 7

// Sensor presence detection pins (active low when sensor is present, using pull-up resistors)
#define PIN_SENSOR_PRS_0 8
#define PIN_SENSOR_PRS_1 9
#define PIN_SENSOR_PRS_2 10

// 2.5V power enable, turn off when no sensor is connected to avoid illegal state on current source
// Unfortunately, this also powers the hall voltage ADC - meaning we need to reconfigure it after each power cycle
#define PIN_POWER_ENABLE_2V5 11

// ADS8866 SPI pins (Temperature ADC)
#define SPI_ADC1 spi1
#define ADC1_MISO 12
#define ADC1_CONVST 13
#define ADC1_SCLK 14
#define ADC1_MOSI 15

// AD7175-2 SPI pins (Hall voltage ADC)
#define SPI_ADC0 spi0
#define ADC0_MISO 16
#define ADC0_SYNC_ERR 17
#define ADC0_SCLK 18
#define ADC0_MOSI 19

// Pico ADC0 (Hall current saturation check)
#define PICO_ADC0 26


/* MACROS */
// Frequency to timer conversion, i.e. how many microseconds to wait in between toggling modulation states for a given frequency
#define FREQUENCY_TO_TIMER_US(f) (500000 / (f))

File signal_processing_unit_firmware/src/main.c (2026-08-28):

// Copyright (c) 2026    Claes Astrabeck, Julius Berg, David Björkman, Nils Palm, Daniel Rising, Hugo Sahlin
// Copyright (c) 2026    ScalinQ AB
//
// This software is released under the MIT License. 
// <https://opensource.org/licenses/MIT>

#include "AD7175_adc.h"
#include "ADS8866_adc.h"
#include "buffers.h"
#include "config.h"
#include "gpio.h"
#include "interface.h"
#include "current_control.h"
#include "sensor.h"
#include "signal_processing.h"

#include <stdio.h>

#include "pico/stdlib.h"
#include "pico/multicore.h"
#include "hardware/adc.h"

// =====================================================================================================================
// Static (Private)
// =====================================================================================================================

static bool do_clean_shutdown = false;
static uint64_t time_last_idle_print = 0;
static float temperature_voltages[NUMBER_OF_SENSORS] = {-1.0f, -1.0f, -1.0f};
static double hall_voltages[NUMBER_OF_SENSORS] = {-1.0, -1.0, -1.0};

static void init() {
    printf("Cryomagsens starting up...\n\n");

    // Initialize stdio for USB output
    stdio_init_all();
    printf("USB initialized.\n");

    // Initialize gpio pins
    init_gpio();
    printf("GPIO initialized.\n");

    // Initialize sensors with PRS interrupts
    init_sensors();
    printf("Sensors initialized.\n");

    // Initialize Pico ADC0
    adc_init();
    adc_gpio_init(PICO_ADC0);
    adc_select_input(0);
    printf("Pico ADC0 (Current saturation check) initialized.\n");

    // Initialize ADS8866 (temperature ADC)
    init_ads8866();
    printf("SPI for ADS8866 (Temperature ADC) initialized.\n");

    // Initialize AD7175 (Hall voltage ADC)
    init_ad7175();
    printf("SPI for AD7175 (Hall voltage ADC) initialized.\n");

    // Enable main power
    gpio_put(PIN_POWER_ENABLE_POS, 1);
    gpio_put(PIN_POWER_ENABLE_NEG, 1);
    printf("Main power enabled.\n");
}

static void print_results() {
    for (int i = 0; i < NUMBER_OF_SENSORS; i++) {
        if (sensor_active[i]) {
            double h = hall_voltages[i];
            float t = temperature_voltages[i];
            printf("Sensor %d: Hall Voltage = %.6f uV, Temperature Voltage = %.6f V\n", i, h, t);
        }
    }
    printf("\n");
}

// =====================================================================================================================
// Main
// =====================================================================================================================

int main()
{
    init();

    /* POLLING LOOP */
    while (true) {

        // --- READ USER COMMANDS ---
        if (read_usb_input()) {
            // Process the command if one was received
            process_command();
        }

        // --- STOP MEASUREMENT ---
        // Clean shutdown ensured all timers are turned off
        if (do_clean_shutdown || (measurement_active && debug_mode) || reboot_measurement_flag) {
            do_clean_shutdown = false;
            measurement_active = false;
            reboot_measurement_flag = false;

            // 1. Stop timers
            stop_current_timer();
            stop_integration_timer();

            // 2. Turn off read-loop
            multicore_reset_core1();

            // 3. Disable power to the current source
            gpio_put(PIN_POWER_ENABLE_2V5, 0);

            // 4. Clear integration timer flag
            integration_timer_flag = false;

            // 5. Just went idle, wait before printing
            time_last_idle_print = time_us_64();

            // 6. Report that a clean shutdown has now occured
            printf("Clean shutdown completed!\n\n");
        }

        // --- START MEASUREMENT ---
        // If we are currently inactive and we have sensors connected we want to start measurement if we ensure:
        // - Sensor connections have not recently changed and not yet been updated
        // - We are not currently waiting for a clean shutdown
        // - We are not manually turned off through the interface
        if (!measurement_active && active_sensors_count && !sensor_presence_changed_flag && !do_clean_shutdown && !debug_mode) {
            printf("Starting measurements...\n");
            measurement_active = true;

            // 1. Enable power to the current source
            // -- Since we run configure_sensors() following sensor_presence_changed, the MUX is currently set to an active sensor.
            gpio_put(PIN_POWER_ENABLE_2V5, 1);

            // 2. Find highest, non-saturated current OR set to a user-defined current level
            // -- If the user defined a specific current it will already be correct and this will do nothing
            // -- If the user defined AUTO, this line will rerun AUTO and make sure it is up to date.
            set_current_level(user_defined_current_level);

            // 3. Reconfigure AD7175 following power cycle
            sleep_ms(100); // Wait for ADC to power up
            configure_ad7175();

            // 4. Start spinning current timer
            start_current_timer();

            // 5. Calibrate real zero
            ad7175_set_zero();

            // 6. Start integration timer
            start_integration_timer();
            sleep_ms(100);

            // 7. Launch the second core to read hall voltage
            multicore_launch_core1(read_loop);

            // 8. Flush buffers
            // - This is timed to the beginning of a spinning current cycle
            consumed_buffer = true; // Mark the new consumer buffer as consumed, since we don't care about its contents
            switch_producer_buffer();
            printf("Measurements started!\n\n");
        }
        
        // --- DATA PROCESSING & SENSOR SWITCH ---
        if (integration_timer_flag) {
            integration_timer_flag = false;

            // 1. Start temperature voltage conversion
            float sum = 0;
            for (int i = 0; i < 10000; i++) {
                ads8866_start_conversion();
                sum += ads8866_get_voltage();
            }

            // 2. Switch buffers
            // - This is timed to the beginning of a spinning current cycle
            switch_producer_buffer();
            
            // 3. Get Hall voltage
            double pre_amp_hall_voltage = calculate_hall_voltage();
            double hall_voltage = pre_amp_hall_voltage / 100; // FIXME:
            double hall_voltage_uV = hall_voltage * 1000000;
            hall_voltages[current_sensor_index] = hall_voltage_uV;

            // 4. Get temperature voltage
            temperature_voltages[current_sensor_index] = sum / 10000;

            // 5. Switch to the next sensor in the MUX
            switch_to_next_sensor();

            // 6. If full rotation is completed
            if (all_sensors_read_flag) {
                all_sensors_read_flag = false;
                print_results();
            }
            
            // 7. Flush buffers
            // - This is timed to the beginning of a spinning current cycle
            flush_buffers();
        }

        // --- UPDATE SENSORS ---
        if (sensor_presence_changed_flag) {
            sensor_presence_changed_flag = false;

            printf("Sensor configuration changed...\n\n");

            sleep_ms(100);

            // Reconfigure sensors and update activity flags
            configure_sensors();

            // At least something changed, we cannot trust the latest data
            // thus we need to reconfigure measurement settings
            
            if (measurement_active) {
                do_clean_shutdown = true;
            }
        }

        // --- IDLE MESSAGE ---
        if (!measurement_active && time_us_64() - time_last_idle_print > 5000000) {

            if (debug_mode) {
                //printf("System is manually turned off. Waiting for user commands...\n\n");
            }
            else {
                printf("System is idle. Waiting for sensor connection...\n");
            }
            time_last_idle_print = time_us_64();
        }
    }
}

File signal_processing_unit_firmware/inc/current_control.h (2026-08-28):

// Copyright (c) 2026    Claes Astrabeck, Julius Berg, David Björkman, Nils Palm, Daniel Rising, Hugo Sahlin
// Copyright (c) 2026    ScalinQ AB
//
// This software is released under the MIT License. 
// <https://opensource.org/licenses/MIT>

#pragma once

#include <stdint.h>
#include <stdbool.h>

// =====================================================================================================================
// Current parameter enumerators
// =====================================================================================================================

// Different spinning current direction states after general direction of the current through the hall element
typedef enum {
    
    // Current traveling from node d -> b
    CURRENT_WEST = 0,
    
    // Current traveling from node b -> d
    CURRENT_EAST = 1,

    // Current traveling from node c -> a
    CURRENT_NORTH = 2,

    // Current traveling from node a -> c
    CURRENT_SOUTH = 3

} SpinningCurrentState;

// Different current level states, this is tied to multiplexer states and hardware resistances
typedef enum {
    CURRENT_AUTO = -1,
    CURRENT_3000_uA = 0,
    CURRENT_300_uA = 1,
    CURRENT_30_uA = 2, 
    CURRENT_8300_uA = 3 
} CurrentLevel;

// =====================================================================================================================
// Global variables
// =====================================================================================================================

// Flag indicating that it's time to switch buffers and calculate results
extern volatile bool integration_timer_flag;

// Flag indicating the stability of the modulation state
// Everytime the current switches direction there will be an "unstable" time where
// the values are unreliable due to transients
extern volatile bool modulation_state_stable;

// Flag indicating the stability of the axis state
// Everytime the current switches axis there will be an "unstable" time where
// the values are unreliable due to transients
extern volatile bool axis_state_stable;

// The state of the spinning current setup
extern volatile SpinningCurrentState spinning_current_state;

// The configured time to integrate for before reporting results
extern volatile uint32_t integration_time_ms; 

// The frequency for which the current should be modulated
// - This is done via a square wave generator using a H-bridge
// - Default freuency should be 7000 Hz, which is tied to 0 phase difference in the analog bandpass filter
extern volatile uint32_t current_polarity_frequency;

// The frequency for which axises over the Hall element should switch
// - This produces big transients where the results are marked as unstable, therefore a lower frequency is prefered
// - Default is 70 Hz changing this value slightly should have little to none impact.
extern volatile uint32_t current_axis_frequency; 

// This is the time for which to wait after switching current modulation state, before noticing the results at through
// the ADC
extern volatile uint32_t modulation_propagation_time_us;

// The time it takes for a current modulation transient to settle
extern volatile uint32_t modulation_unstable_time_us; 

// The time it takes for an axis switch transient to settle
extern volatile uint32_t axis_unstable_time_us;

// The configured current level
extern volatile CurrentLevel user_defined_current_level;

// =====================================================================================================================
// Functions
// =====================================================================================================================

// Starts the current modulation/axis switching timer
// - This also triggers the axis switching at the required intervals
// - and updates unstable times and current direction states accordingly
void start_current_timer(void);

// Stops the current modulation/axis switching
void stop_current_timer(void);

// Updates the multiplexers to the specified current level state
void set_current_level(CurrentLevel level);

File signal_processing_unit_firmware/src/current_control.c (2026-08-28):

// Copyright (c) 2026    Claes Astrabeck, Julius Berg, David Björkman, Nils Palm, Daniel Rising, Hugo Sahlin
// Copyright (c) 2026    ScalinQ AB
//
// This software is released under the MIT License. 
// <https://opensource.org/licenses/MIT>

#include "current_control.h"

#include "config.h"

#include "pico/stdlib.h"

// =====================================================================================================================
// Static (Private)
// =====================================================================================================================

static repeating_timer_t current_timer;

// Counts the current modulation switches
static int switch_counter = 0;

// The threshhold of current modulation switches for which to switch axis
static int switch_threshold = 0;

static int64_t axis_unstable_callback(alarm_id_t id, void *user_data) {
    axis_state_stable = true;
    return 0;
}

static int64_t modulation_unstable_callback(alarm_id_t id, void *user_data) {
    modulation_state_stable = true;
    return 0;
}

static int64_t modulation_propagated_callback(alarm_id_t id, void *user_data) {
    
    // Transient has just now propagated, state is unstable for the specified time
    modulation_state_stable = false;

    // Current change has propagated, apply new state
    SpinningCurrentState new_state = (SpinningCurrentState)(uintptr_t)user_data;
    spinning_current_state = new_state;

    // Alarm to mark the state as stable again
    add_alarm_in_us(
        modulation_unstable_time_us, 
        modulation_unstable_callback, 
        NULL, 
        true
    );
    return 0; 
}

static bool current_timer_callback(repeating_timer_t *rt) {
    // Switch current modulation state
    gpio_put(PIN_CURRENT_DIRECTION, !gpio_get(PIN_CURRENT_DIRECTION));

    // Increment counter to record when it's time to switch axis
    switch_counter++;
    
    if (switch_counter >= switch_threshold) {
        // Switch axis state
        gpio_put(PIN_CURRENT_AXIS, !gpio_get(PIN_CURRENT_AXIS));

        // Reset counter
        switch_counter = 0;

        // Instantly mark state as unstable
        // (Technically this could wait for the propagation time as well, but that's a small optimization)
        axis_state_stable = false;

        // Alarm to mark state as stable again
        add_alarm_in_us(
            axis_unstable_time_us, 
            axis_unstable_callback, 
            NULL, 
            true
        );
    }   
    
    // The state that the system will be in once the change has propagated
    uint8_t pending_state = (gpio_get(PIN_CURRENT_AXIS) << 1) | gpio_get(PIN_CURRENT_DIRECTION);
    
    // Set alarm for when the change has propagated
    add_alarm_in_us(
        modulation_propagation_time_us,
        modulation_propagated_callback, 
        (void *)(uintptr_t)pending_state, 
        true
    );

    return true;
}

// =====================================================================================================================
// API (Public)
// =====================================================================================================================

// Current state
volatile bool modulation_state_stable = true;
volatile bool axis_state_stable = true;
volatile SpinningCurrentState spinning_current_state = CURRENT_SOUTH;

// Parameters
volatile uint32_t integration_time_ms = DEFAULT_INTEGRATION_TIME_MS; 
volatile uint32_t current_polarity_frequency = DEFAULT_CURRENT_POLARITY_FREQUENCY;
volatile uint32_t current_axis_frequency = DEFAULT_CURRENT_AXIS_FREQUENCY; 
volatile uint32_t modulation_propagation_time_us = DEFAULT_MODULATION_PROPAGATION_TIME_US;
volatile uint32_t modulation_unstable_time_us = DEFAULT_MODULATION_UNSTABLE_TIME_US;
volatile uint32_t axis_unstable_time_us = DEFAULT_AXIS_UNSTABLE_TIME_US;
volatile CurrentLevel user_defined_current_level = CURRENT_3000_uA;

void start_current_timer() {
    // Calculate the axis switching threshold, the polarity switch period and reset the counter
    switch_counter = 0;
    switch_threshold = current_polarity_frequency / current_axis_frequency;
    int polarity_period_us = FREQUENCY_TO_TIMER_US(current_polarity_frequency);

    // Start modulation timer
    add_repeating_timer_us(
        -polarity_period_us, 
        current_timer_callback, 
        NULL, 
        &current_timer
    );
}

void stop_current_timer(void) {
    cancel_repeating_timer(&current_timer);
}

void set_current_level(CurrentLevel level) {

    user_defined_current_level = level;

    switch (level)
    {
    case CURRENT_3000_uA:
        user_defined_current_level = CURRENT_3000_uA;
        gpio_put(PIN_CURRENT_LEVEL_0, 0);
        gpio_put(PIN_CURRENT_LEVEL_1, 0);
        break;

    case CURRENT_300_uA:
        user_defined_current_level = CURRENT_300_uA;
        gpio_put(PIN_CURRENT_LEVEL_0, 1);
        gpio_put(PIN_CURRENT_LEVEL_1, 0);
        break;

    case CURRENT_30_uA:
        user_defined_current_level = CURRENT_30_uA;
        gpio_put(PIN_CURRENT_LEVEL_0, 0);
        gpio_put(PIN_CURRENT_LEVEL_1, 1);
        break;

    case CURRENT_8300_uA:
        user_defined_current_level = CURRENT_8300_uA;
        gpio_put(PIN_CURRENT_LEVEL_0, 1);
        gpio_put(PIN_CURRENT_LEVEL_1, 1);
        break;

    case CURRENT_AUTO:

        break;

    default:
        break;
    }
}

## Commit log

2026-08-28 Wrote readme for sensor unit
2026-08-28 Added hall voltage logging to the SPU logging script + changed its name to SPU_logging

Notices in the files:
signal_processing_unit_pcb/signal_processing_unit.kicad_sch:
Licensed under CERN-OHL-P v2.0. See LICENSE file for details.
